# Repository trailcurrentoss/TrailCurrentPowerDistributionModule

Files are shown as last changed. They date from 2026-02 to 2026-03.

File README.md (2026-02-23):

# TrailCurrent Power Distribution Module

CAN-controlled 8-channel PWM power distribution module for vehicle lighting and accessory control with OTA firmware update capability. Part of the [TrailCurrent](https://trailcurrent.com) open-source vehicle platform.

## Hardware Overview

- **Microcontroller:** ESP32 (WROOM32)
- **Function:** 8-channel PWM lighting/accessory controller with CAN bus interface
- **Key Features:**
  - 8 independent MOSFET-driven PWM outputs (0-255 brightness)
  - CAN bus communication at 500 kbps
  - Individual and master on/off/brightness control
  - Animated light sequences (startup, interior, exterior)
  - Over-the-air (OTA) firmware updates via WiFi
  - WiFi credentials provisioned dynamically over CAN bus
  - Hierarchical PCB schematic design (5 sheets)

## Hardware Requirements

### Components

- **Microcontroller:** ESP32 development board
- **CAN Transceiver:** Vehicle CAN bus interface (TX: GPIO 15, RX: GPIO 13)
- **MOSFET Drivers:** 8 channels for PWM output switching
- **DIP Switches:** Configuration switches

### Pin Connections

**PWM Outputs:**

| GPIO | Function |
|---|---|
| 32 | Output 1 |
| 33 | Output 2 |
| 26 | Output 3 |
| 14 | Output 4 |
| 4 | Output 5 |
| 17 | Output 6 |
| 19 | Output 7 |
| 23 | Output 8 |

### KiCAD Library Dependencies

This project uses the consolidated [TrailCurrentKiCADLibraries](https://github.com/trailcurrentoss/TrailCurrentKiCADLibraries).

**Setup:**

```bash
# Clone the library
git clone git@github.com:trailcurrentoss/TrailCurrentKiCADLibraries.git

# Set environment variables (add to ~/.bashrc or ~/.zshrc)
export TRAILCURRENT_SYMBOL_DIR="/path/to/TrailCurrentKiCADLibraries/symbols"
export TRAILCURRENT_FOOTPRINT_DIR="/path/to/TrailCurrentKiCADLibraries/footprints"
export TRAILCURRENT_3DMODEL_DIR="/path/to/TrailCurrentKiCADLibraries/3d_models"
```

See [KICAD_ENVIRONMENT_SETUP.md](https://github.com/trailcurrentoss/TrailCurrentKiCADLibraries/blob/main/docs/KICAD_ENVIRONMENT_SETUP.md) in the library repository for detailed setup instructions.

## Opening the Project

1. **Set up environment variables** (see Library Dependencies above)
2. **Open KiCAD:**
   ```bash
   kicad EDA/trailer-power-control-system.kicad_pro
   ```
3. **Verify libraries load** - All symbol and footprint libraries should resolve without errors
4. **View 3D models** - Open PCB and press `Alt+3` to view the 3D visualization

### Schematic Sheets

The design uses a hierarchical schematic with dedicated sheets:
- **Root** - Top-level connections
- **Power** - Power distribution and regulation
- **CAN** - CAN bus transceiver interface
- **MCU** - ESP32 microcontroller and support circuits
- **MOSFETs** - 8-channel MOSFET driver outputs
- **DIP Switch** - Configuration switches

## Firmware

See `src/` directory for PlatformIO-based firmware.

**Setup:**
```bash
# Install PlatformIO (if not already installed)
pip install platformio

# Build firmware
pio run

# Upload to board (serial)
pio run -t upload

# Upload via OTA (after initial flash)
pio run -t upload --upload-port esp32-DEVICE_ID
```

### Firmware Dependencies

This firmware depends on the following public libraries:

- **[OtaUpdateLibraryWROOM32](https://github.com/trailcurrentoss/OtaUpdateLibraryWROOM32)** (v0.0.1) - Over-the-air firmware update functionality
- **[TwaiTaskBasedLibraryWROOM32](https://github.com/trailcurrentoss/TwaiTaskBasedLibraryWROOM32)** (v0.0.1) - CAN bus communication interface
- **[ESP32ArduinoDebugLibrary](https://github.com/trailcurrentoss/ESP32ArduinoDebugLibrary)** (v2.0.0) - Debug macro system with compile-time removal

All dependencies are automatically resolved by PlatformIO during the build process.

### Serial Debugging

Debug output is controlled by the `DEBUG` build flag in `platformio.ini`:

```ini
build_flags = -DDEBUG=1   ; Enable debug output (default)
; build_flags = -DDEBUG=0  ; Disable — all debug calls compile away to zero overhead
```

When enabled, debug macros (`debugln()`, `debugf()`, `debug_tag()`, etc.) output to Serial at 115200 baud. When disabled (`DEBUG=0`), all debug code is completely removed at compile time with no performance or flash size impact.

**WiFi Credentials:**
- WiFi credentials are provisioned dynamically via CAN bus (Message ID 0x01)
- Credentials are stored in NVS (non-volatile storage) and persist across reboots
- For standalone testing, credentials can be set manually in firmware

### CAN Bus Protocol

**Receive (Bus to Module):**

| CAN ID | Description |
|---|---|
| 0x00 | OTA update trigger (MAC-based device targeting) |
| 0x01 | WiFi credential provisioning (SSID/password via CAN) |
| 0x18 | Toggle channel on/off (byte 0 = channel 0-7, 8=all on, 9=all off) |
| 0x21 | Set brightness (byte 0 = channel, byte 1 = PWM value 0-255) |
| 0x1E | Trigger light sequence (interior/exterior animations) |

**Transmit (Module to Bus):**

| CAN ID | Description |
|---|---|
| 0x1B | Status report - current PWM values for all 8 channels (8 bytes) |

## Manufacturing

- **PCB Files:** Ready for fabrication via standard PCB services (JLCPCB, OSH Park, etc.)
- **BOM Generation:** Export BOM from KiCAD schematic (Tools > Generate BOM)
- **JLCPCB Assembly:** See [BOM_ASSEMBLY_WORKFLOW.md](https://github.com/trailcurrentoss/TrailCurrentKiCADLibraries/blob/main/tools/BOM_ASSEMBLY_WORKFLOW.md) for detailed assembly workflow

## Project Structure

```
├── EDA/                          # KiCAD hardware design files
│   ├── trailer-power-control-system.kicad_pro
│   ├── trailer-power-control-system.kicad_sch  # Root schematic
│   ├── can.kicad_sch             # CAN subsystem
│   ├── mcu.kicad_sch             # MCU subsystem
│   ├── power.kicad_sch           # Power subsystem
│   ├── mosfets.kicad_sch         # 8-channel MOSFET drivers
│   ├── dip_switch.kicad_sch      # Configuration switches
│   └── trailer-power-control-system.kicad_pcb  # PCB layout
├── src/                          # Firmware source
│   ├── main.cpp                  # Main application
│   ├── globals.h                 # Pin definitions
│   ├── canHelper.h               # CAN message handling
│   ├── lightSequences.h          # Startup and animated light sequences
│   └── wifiConfig.h              # NVS WiFi credential storage
├── data/
│   └── partitions.csv            # ESP32 flash partition layout
└── platformio.ini                # Build configuration
```

## License

MIT License - See LICENSE file for details.

This is open source hardware. You are free to use, modify, and distribute these designs under the terms of the MIT license.

## Contributing

Improvements and contributions are welcome! Please submit issues or pull requests.

## Support

For questions about:
- **KiCAD setup:** See [KICAD_ENVIRONMENT_SETUP.md](https://github.com/trailcurrentoss/TrailCurrentKiCADLibraries/blob/main/docs/KICAD_ENVIRONMENT_SETUP.md)
- **Assembly workflow:** See [BOM_ASSEMBLY_WORKFLOW.md](https://github.com/trailcurrentoss/TrailCurrentKiCADLibraries/blob/main/tools/BOM_ASSEMBLY_WORKFLOW.md)

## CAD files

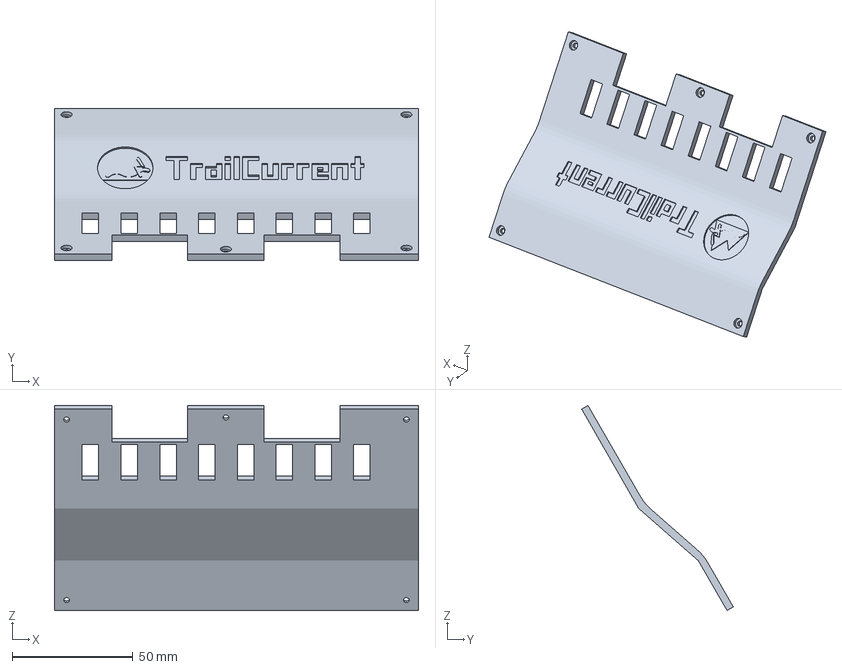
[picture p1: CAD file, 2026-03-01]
CAD/trailer-power-distribution-module-case-BodyContouredCover.3mf
150.5 x 62.7 x 84.8 mm

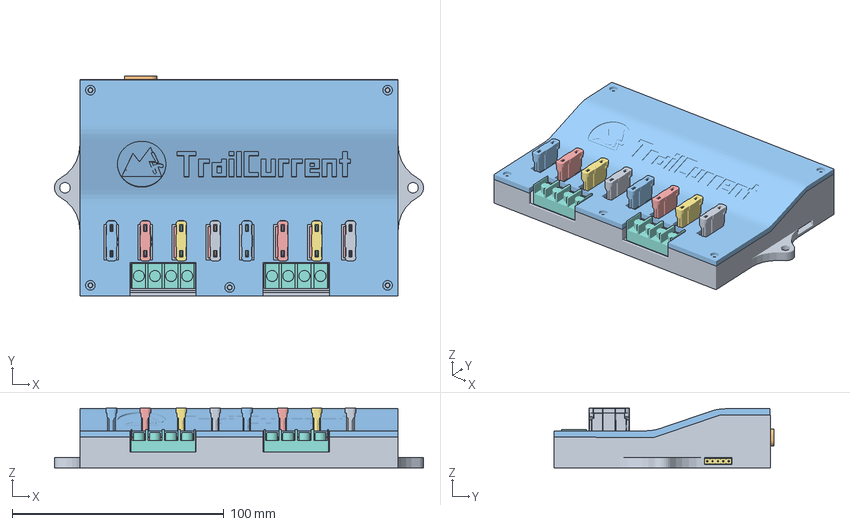
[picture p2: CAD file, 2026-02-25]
CAD/trailer-power-distribution-module-case.FCStd
174.4 x 103.9 x 28.3 mm
Pcb_a65b
topPads_a65b
topTracks_a65b
botPads_a65b_cut
J5_Body_9aade6df98ed x 8
C4_C_1206_3216Metric_15ba0ad3e721 x 6
R8_R_1206_3216Metric_e07121ee4934 x 18
Q5_IRF4905STRLPBF_7185022933cc x 8
U5_DIP-4_W7.62mm_ebb48af450fe x 8
AP63203WU-7
AP63203WU-008
AP63203WU-009
AP63203WU-010
AP63203WU-011
AP63203WU-012
AP63203WU-013
AP63203WU-014
U1_ESP32-WROOM-32_2e14fae01c0c
U2_SOIC_8_39x49mm_P127mm_15ada4e996ee
FilletPin1
FilletPin2
J1_PinHeader_1x06_P254mm_Horizontal_2a81e018bd7b
J8_Body_1469dcacabcb x 2
BodyCaseBottom
XT60E-M
ATOF Blade Fuse
ATOF Blade Fuse001
ATOF Blade Fuse004
ATOF Blade Fuse005
ATOF Blade Fuse007
ATOF Blade Fuse008
ATOF Blade Fuse010
ATOF Blade Fuse011
ATOF Blade Fuse013
ATOF Blade Fuse014
ATOF Blade Fuse016
ATOF Blade Fuse017
ATOF Blade Fuse019
ATOF Blade Fuse020
ATOF Blade Fuse022
ATOF Blade Fuse023
BodyContouredCover (Meshed)

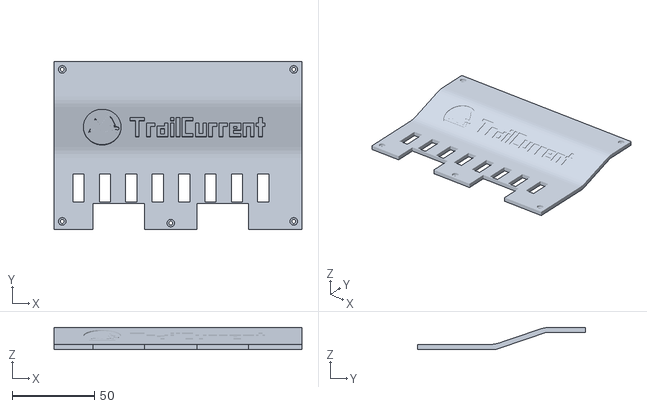
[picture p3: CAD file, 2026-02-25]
CAD/BodyContouredCover.stl
150.5 x 102.2 x 13.6

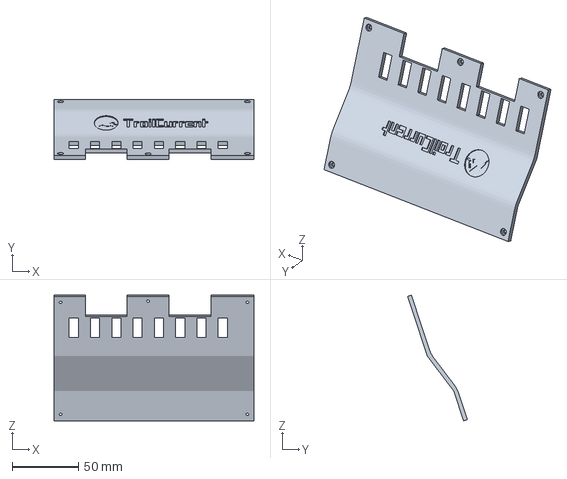
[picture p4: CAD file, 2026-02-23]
CAD/TrailCurrentPowerDistributionModule.3mf
150.5 x 45.0 x 94.6 mm

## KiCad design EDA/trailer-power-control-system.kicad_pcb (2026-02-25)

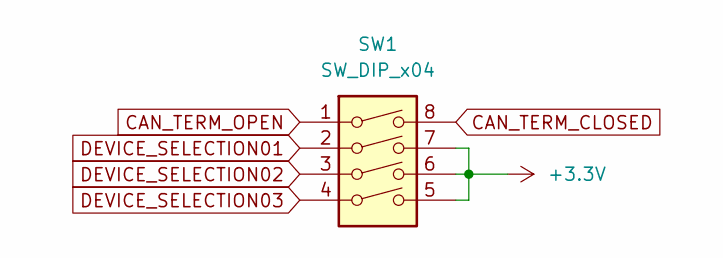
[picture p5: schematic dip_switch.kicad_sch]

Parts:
SW1: SW_DIP_x04; SW_DIP_219-4LPST

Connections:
+3.3V: SW1.5, SW1.6, SW1.7; also elsewhere on the board
CANL: SW1.1; also elsewhere on the board
CAN_TERM_CLOSED: SW1.8; also elsewhere on the board
DEVICE_SELECTION01: SW1.2; also elsewhere on the board
DEVICE_SELECTION02: SW1.3; also elsewhere on the board
DEVICE_SELECTION03: SW1.4; also elsewhere on the board

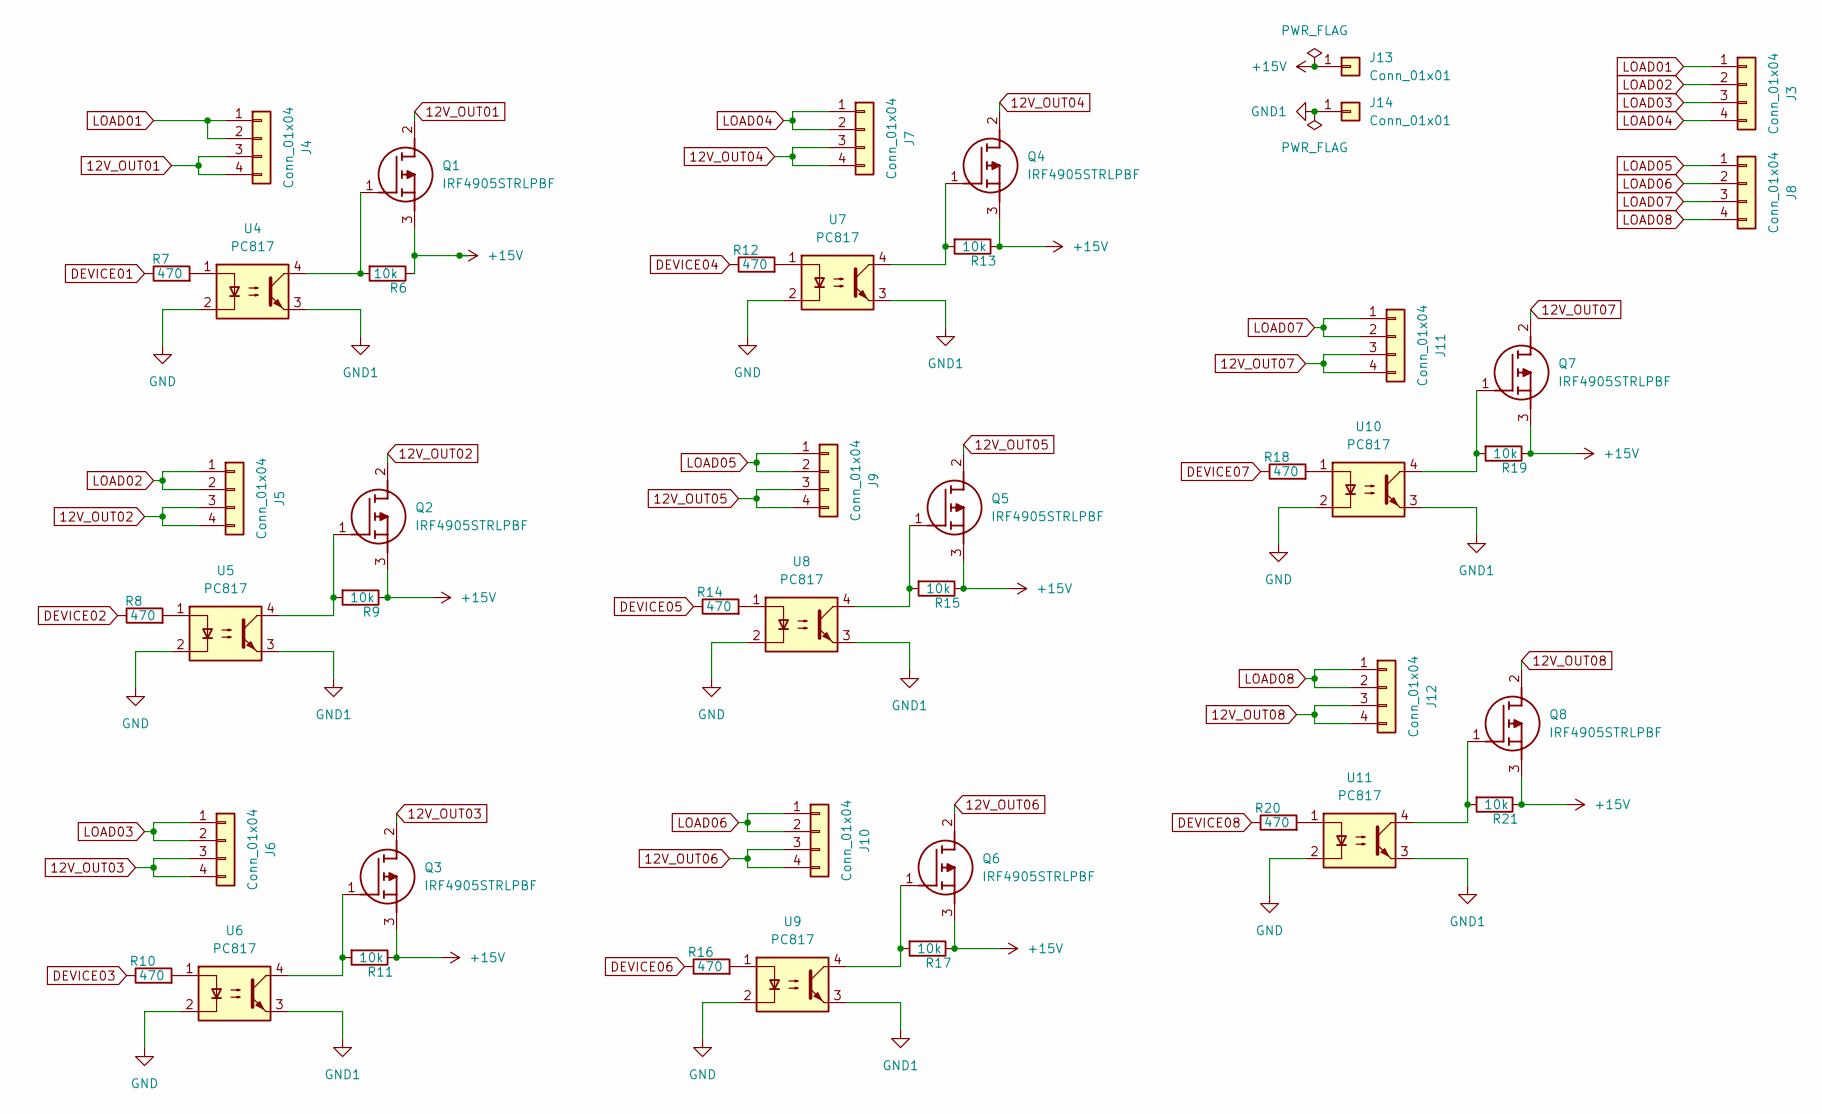
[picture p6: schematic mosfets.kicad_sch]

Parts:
J3, J8: Conn_01x04; Screw_Terminal_1x04
J4, J5, J6, J7, J9, J10, J11, J12: Conn_01x04; Automotive_Fuse_Holder
J13, J14: Conn_01x01; TestPoint_7.77mmX7.77mm
Q1, Q2, Q3, Q4, Q5, Q6, Q7, Q8: IRF4905STRLPBF; Mouser Part Number 942-IRF4905STRLPBF
R6, R9, R11, R13, R15, R17, R19, R21: 10k; R_1206_3216Metric_Pad1.30x1.75mm_HandSolder
R7, R8, R10, R12, R14, R16, R18, R20: 470; R_1206_3216Metric_Pad1.30x1.75mm_HandSolder
U4, U5, U6, U7, U8, U9, U10, U11: PC817; PC817X3CSP9F

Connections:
12V_OUT01: J4.3, J4.4, Q1.2 (D)
12V_OUT02: J5.3, J5.4, Q2.2 (D)
12V_OUT03: J6.3, J6.4, Q3.2 (D)
12V_OUT04: J7.3, J7.4, Q4.2 (D)
12V_OUT05: J9.3, J9.4, Q5.2 (D)
12V_OUT06: J10.3, J10.4, Q6.2 (D)
12V_OUT07: J11.3, J11.4, Q7.2 (D)
12V_OUT08: J12.3, J12.4, Q8.2 (D)
+15V: J13.1, Q1.3 (S), Q2.3 (S), Q3.3 (S), Q4.3 (S), Q5.3 (S), Q6.3 (S), Q7.3 (S), Q8.3 (S), R6.1, R9.1, R11.1, R13.1, R15.1, R17.1, R19.1, R21.1
DEVICE01: R7.1; also elsewhere on the board
DEVICE02: R8.1; also elsewhere on the board
DEVICE03: R10.1; also elsewhere on the board
DEVICE04: R12.1; also elsewhere on the board
DEVICE05: R14.1; also elsewhere on the board
DEVICE06: R16.1; also elsewhere on the board
DEVICE07: R18.1; also elsewhere on the board
DEVICE08: R20.1; also elsewhere on the board
GND: U4.2, U5.2, U6.2, U7.2, U8.2, U9.2, U10.2, U11.2; also elsewhere on the board
GND1: J14.1, U4.3, U5.3, U6.3, U7.3, U8.3, U9.3, U10.3, U11.3
LOAD01: J3.1, J4.1, J4.2
LOAD02: J3.2, J5.1, J5.2
LOAD03: J3.3, J6.1, J6.2
LOAD04: J3.4, J7.1, J7.2
LOAD05: J8.1, J9.1, J9.2
LOAD06: J8.2, J10.1, J10.2
LOAD07: J8.3, J11.1, J11.2
LOAD08: J8.4, J12.1, J12.2
unnamed: Q1.1 (G), R6.2, U4.4
unnamed: Q2.1 (G), R9.2, U5.4
unnamed: Q3.1 (G), R11.2, U6.4
unnamed: Q4.1 (G), R13.2, U7.4
unnamed: Q5.1 (G), R15.2, U8.4
unnamed: Q6.1 (G), R17.2, U9.4
unnamed: Q7.1 (G), R19.2, U10.4
unnamed: Q8.1 (G), R21.2, U11.4
unnamed: R7.2, U4.1
unnamed: R8.2, U5.1
unnamed: R10.2, U6.1
unnamed: R12.2, U7.1
unnamed: R14.2, U8.1
unnamed: R16.2, U9.1
unnamed: R18.2, U10.1
unnamed: R20.2, U11.1

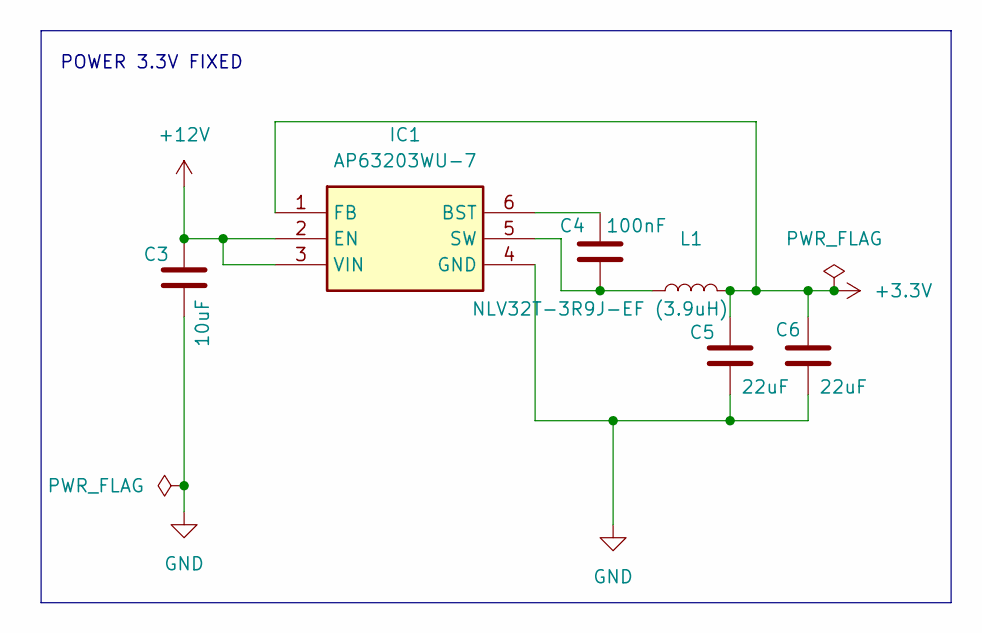
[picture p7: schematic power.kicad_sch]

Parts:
C3: 10uF; C_1206_3216Metric
C4: 100nF; C_1206_3216Metric
C5, C6: 22uF; C_1206_3216Metric_Pad1.33x1.80mm_HandSolder
IC1: AP63203WU-7; AP63203WU7; Mouser Part Number 621-AP63203WU-7
L1: NLV32T-3R9J-EF (3.9uH); NLV32T-3R9J-EF

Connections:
+3.3V: C5.1, C6.1, IC1.1 (FB), L1.2; also elsewhere on the board
+12V: C3.1, IC1.2 (EN), IC1.3 (VIN); also elsewhere on the board
GND: C3.2, C5.2, C6.2, IC1.4 (GND); also elsewhere on the board
unnamed: C4.1, IC1.6 (BST)
unnamed: C4.2, IC1.5 (SW), L1.1

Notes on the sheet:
POWER 3.3V FIXED

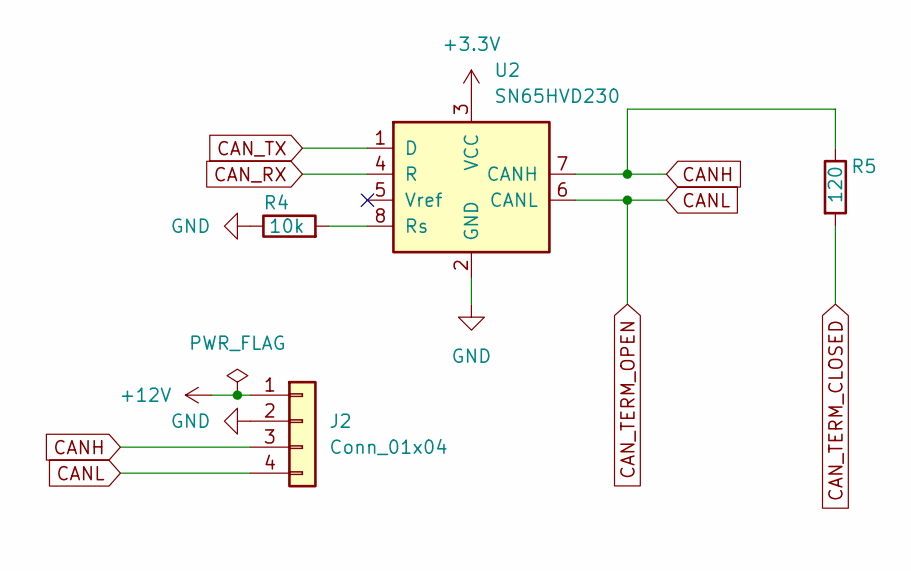
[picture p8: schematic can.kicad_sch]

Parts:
J2: Conn_01x04; CAN_PLUS_POWER
R4: 10k; R_1206_3216Metric_Pad1.30x1.75mm_HandSolder
R5: 120; R_1206_3216Metric_Pad1.30x1.75mm_HandSolder
U2: SN65HVD230; SOIC-8_3.9x4.9mm_P1.27mm

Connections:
+3.3V: U2.3 (VCC); also elsewhere on the board
+12V: J2.1; also elsewhere on the board
CANH: J2.3, R5.1, U2.7 (CANH)
CANL: J2.4, U2.6 (CANL); also elsewhere on the board
CAN_RX: U2.4 (R); also elsewhere on the board
CAN_TERM_CLOSED: R5.2; also elsewhere on the board
CAN_TX: U2.1 (D); also elsewhere on the board
GND: J2.2, R4.1, U2.2 (GND); also elsewhere on the board
unnamed: R4.2, U2.8 (Rs)

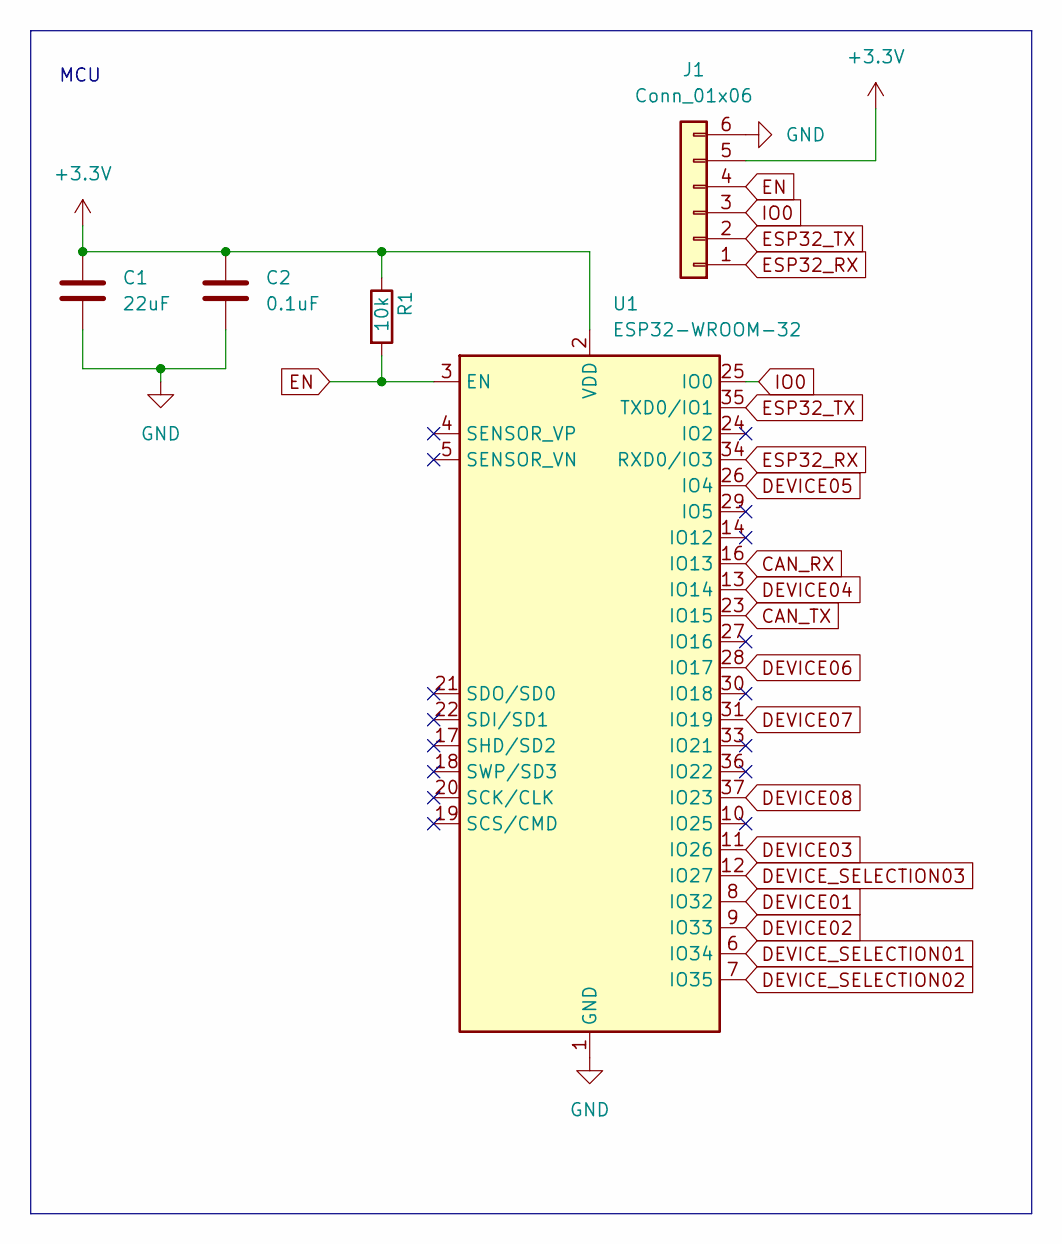
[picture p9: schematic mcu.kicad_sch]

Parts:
C1: 22uF; C_1206_3216Metric_Pad1.33x1.80mm_HandSolder
C2: 0.1uF; C_1206_3216Metric_Pad1.33x1.80mm_HandSolder
J1: Conn_01x06; PinHeader_1x06_P2.54mm_Horizontal
R1: 10k; R_1206_3216Metric_Pad1.30x1.75mm_HandSolder
U1: ESP32-WROOM-32; ESP32-WROOM-32U

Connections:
+3.3V: C1.1, C2.1, J1.5, R1.1, U1.2 (VDD); also elsewhere on the board
CAN_RX: U1.16 (IO13); also elsewhere on the board
CAN_TX: U1.23 (IO15); also elsewhere on the board
DEVICE01: U1.8 (IO32); also elsewhere on the board
DEVICE02: U1.9 (IO33); also elsewhere on the board
DEVICE03: U1.11 (IO26); also elsewhere on the board
DEVICE04: U1.13 (IO14); also elsewhere on the board
DEVICE05: U1.26 (IO4); also elsewhere on the board
DEVICE06: U1.28 (IO17); also elsewhere on the board
DEVICE07: U1.31 (IO19); also elsewhere on the board
DEVICE08: U1.37 (IO23); also elsewhere on the board
DEVICE_SELECTION01: U1.6 (IO34); also elsewhere on the board
DEVICE_SELECTION02: U1.7 (IO35); also elsewhere on the board
DEVICE_SELECTION03: U1.12 (IO27); also elsewhere on the board
EN: J1.4, R1.2, U1.3 (EN)
ESP32_RX: J1.1, U1.34 (RXD0/IO3)
ESP32_TX: J1.2, U1.35 (TXD0/IO1)
GND: C1.2, C2.2, J1.6, U1.1 (GND), U1.15 (GND), U1.38 (GND), U1.39 (GND); also elsewhere on the board
IO0: J1.3, U1.25 (IO0)

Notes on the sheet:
MCU

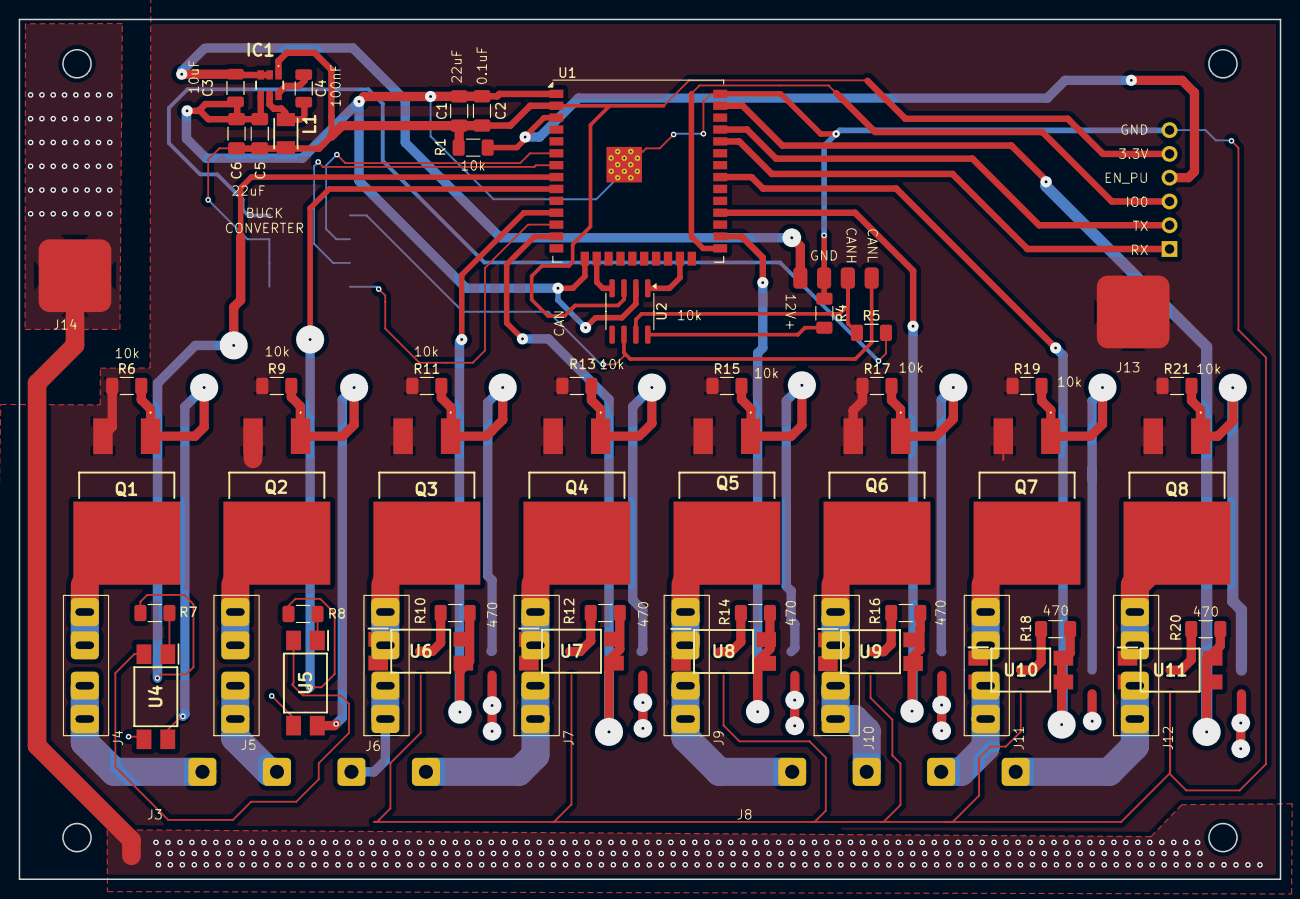
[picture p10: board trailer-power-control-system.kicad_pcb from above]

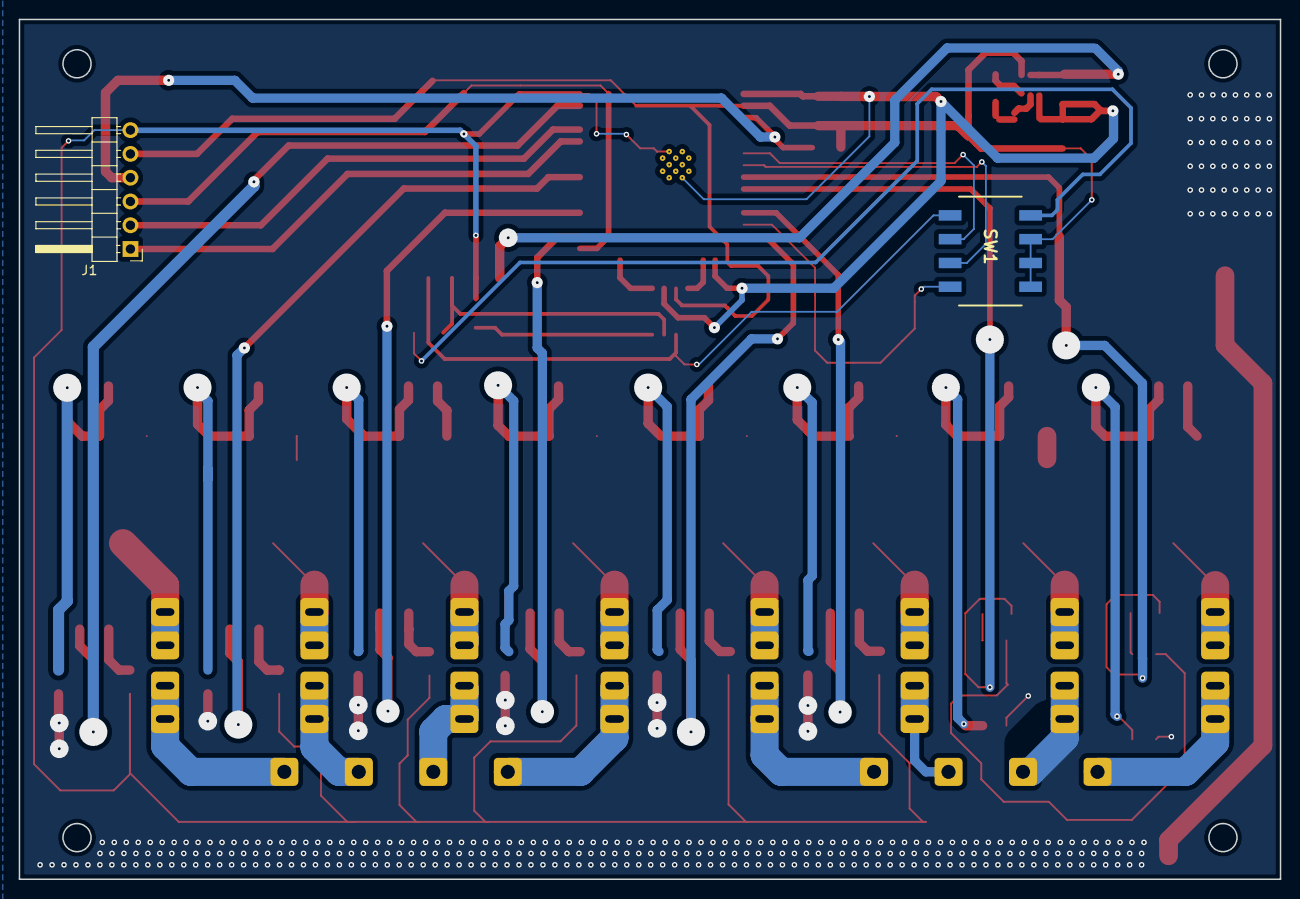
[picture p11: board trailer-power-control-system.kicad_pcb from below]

Board: 2 copper layers, 134.7 x 91.9 mm, 60 parts (2 on the bottom side), 60 nets.

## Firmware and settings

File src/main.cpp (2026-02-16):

#include <debug.h>
#include "globals.h"
#include "canHelper.h"
#include <OtaUpdate.h>
#include "lightSequences.h"
#include "wifiConfig.h"

// Global credential buffers - writable at runtime
char runtimeSsid[33] = {0};
char runtimePassword[64] = {0};

// Create OTA update handler (3-minute timeout, 180000 ms)
OtaUpdate otaUpdate(180000, runtimeSsid, runtimePassword);

void setup()
{
  Serial.begin(115200);

#if DEBUG == 1
  // Wait for serial monitor connection (up to 3 seconds)
  // Ensures startup messages are visible when monitor connects after boot
  unsigned long serialWait = millis();
  while (!Serial.available() && (millis() - serialWait < 3000)) {
    delay(10);
  }
#endif

  debugln("\n=== TrailCurrent Power Control Module ===");
  debugln("CAN-Controlled 8-Channel PWM Lighting");

  // Initialize WiFi config storage and load stored credentials
  wifiConfig::init();
  wifiConfig::setRuntimeCredentialPtrs(runtimeSsid, runtimePassword);

  // Load credentials from NVS (provisioned via CAN bus message 0x01)
  if (wifiConfig::loadCredentials(runtimeSsid, runtimePassword)) {
    debugln("[WiFi] Loaded credentials from NVS");
  } else {
    debugln("[WiFi] No credentials in NVS - OTA disabled until provisioned via CAN");
  }

  // Initialize output pins
  pinMode(OUTPUT01_PIN, OUTPUT);
  pinMode(OUTPUT02_PIN, OUTPUT);
  pinMode(OUTPUT03_PIN, OUTPUT);
  pinMode(OUTPUT04_PIN, OUTPUT);
  pinMode(OUTPUT05_PIN, OUTPUT);
  pinMode(OUTPUT06_PIN, OUTPUT);
  pinMode(OUTPUT07_PIN, OUTPUT);
  pinMode(OUTPUT08_PIN, OUTPUT);

  // Run the startup light show
  debugln("[LIGHTS] Starting 30-second light show...");
  //lightSequences::startupLightShow();
  debugln("[LIGHTS] Light show complete!");

  // Initialize OTA (connects to WiFi)
  debugf("[OTA] Device hostname: %s\n", otaUpdate.getHostName().c_str());
  debugln("[OTA] Ready to receive OTA trigger (CAN ID 0x0)");

  // Initialize CAN
  canHelper::setupCan();

  debugln("=== Setup Complete ===\n");
}

void loop()
{
  canHelper::canLoop();
  canHelper::send_status_message();
}

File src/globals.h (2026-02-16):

#pragma once
#include <Arduino.h>
#include <debug.h>

// ============================================================================
// Output Pin Definitions
// ============================================================================
#define OUTPUT01_PIN 32
#define OUTPUT02_PIN 33
#define OUTPUT03_PIN 26
#define OUTPUT04_PIN 14
#define OUTPUT05_PIN 4
#define OUTPUT06_PIN 17
#define OUTPUT07_PIN 19
#define OUTPUT08_PIN 23

namespace globals {
  // Global constants and utilities can go here
}

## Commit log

2026-02-12 Initial commit: Clean migration to public Codeberg repository
    This is a fresh start on Codeberg with all security and configuration
    issues addressed:
    Security fixes:
    - Removed all git history (fresh start)
    - No personal paths or credentials exposed
    - All WiFi secrets in .gitignore (using secrets.h.example pattern)
    - Private keys protected
    - Internal URLs replaced with public Codeberg references
    Configuration updates:
    - Updated all GitHub references to Codeberg
    - KiCAD projects use environment variables for library paths
    - Platform IO dependencies point to public repositories
    - All .gitignore files comprehensive
    Ready for public use.
    [can.kicad_sch, dip_switch.kicad_sch, mcu.kicad_sch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]
2026-02-13 Updated to align with the new approach of using the edge device to configure OTA WiFi and transmit to this devie over CAN Bus
    [partitions.csv]
2026-02-16 Switched to debug library and twai with freertos task
2026-02-22 Bringing CAD model back in
    [trailer-power-distribution-module-case.FCStd]
2026-02-23 Logo added to case and work started to update the EDA
    [BodyContouredCover.stl, TrailCurrentPowerDistributionModule.3mf, trailer-power-control-system.kicad_pcb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]
2026-02-25 Fixed paths to KiCAD components
    [BodyContouredCover.stl, trailer-power-control-system.kicad_pcb, trailer-power-distribution-module-case-BodyContouredCover.3mf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]
2026-03-01 Added logo to cover with correct orientation for printing
    [trailer-power-distribution-module-case-BodyContouredCover.3mf]
